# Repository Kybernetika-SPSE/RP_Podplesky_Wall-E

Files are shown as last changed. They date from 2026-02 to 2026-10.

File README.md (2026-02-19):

# WALL-E Replica (Ročníkový Projekt)

Toto je repozitář pro stavbu funkční repliky robota WALL-E. Projekt klade důraz na robustní mechanickou konstrukci a moderní elektroniku.

## 🛠️ O Projektu
Cílem je vytvořit **Repliku robota Wall-E**, pomocí 3D tisku a obráběného kovu
*   **Šasi:** Ocelové pláty (Laser cut) + 3D tisk
*   **Podvozek:** Pásový system s nezávislým odpružením 
*   **Mozek:** Nvidia Jetson Orin Nano

## ⚙️ Hardware Specifikace
*   **Pohon:** 2x Motor JGB37-550 (12V, 160 RPM)
*   **Drivery:** 2x BTS7960B (43A H-Bridge)
*   **PWM Řízení:** PCA9685 (I2C)
*   **Napájení:** Duální systém (2x Li-Po 3S 3500mAh)
*   **Ovládání:** Bezdrátová myš / Gamepad

## 💻 Software
Software běží na **Nvidia Jetson** v jazyce **C++**.
*   Využívá **I2C** pro komunikaci s PCA9685.
*   Čte vstupy z `/dev/input/eventX` (myš/klávesnice).
*   Implementuje **Smooth Start/Stop** pro plynulý rozjezd pásů.
*   Zdrojové kódy naleznete ve složce [`code/`](./code).

## 📂 Struktura Repozitáře
*   [`code/`](./code) - Zdrojové kódy ovládacího softwaru (C++, CMake).
*   [`Dokumentace/`](./Dokumentace) - Technické specifikace, schémata zapojení a plány.
*   [`MODEL/`](./MODEL) - 3D Modely (Inventor/STEP) a podklady pro tisk.
*   [`komponenty.md`](./komponenty.md) - Seznam použitých dílů (BOM).

---
**Status:** 🚧 Ve vývoji (Mechanika 60%, Elektronika 40%, Software 20%)

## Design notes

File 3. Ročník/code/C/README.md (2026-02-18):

# WALL-E Jetson Control Code

This directory contains the C++ control software for the WALL-E robot using Nvidia Jetson.

## Requirements
*   **Hardware:**
    *   Nvidia Jetson (Nano / Orin Nano)
    *   PCA9685 PWM Driver (Connected via I2C Bus 1)
    *   SteelSeries Rival 3 Wireless Mouse (or compatible)
    *   BTS7960 Motor Drivers

*   **Software Dependencies:**
    *   `i2c-tools` & `libi2c-dev`
    *   `libevdev-dev`
    *   `cmake`
    *   `g++`

    Install command:
    ```bash
    sudo apt-get update
    sudo apt-get install -y i2c-tools libi2c-dev libevdev-dev cmake g++
    ```

## Wiring (PCA9685)
*   **SDA:** Pin 3 (Bus 1)
*   **SCL:** Pin 5 (Bus 1)
*   **VCC:** 3.3V
*   **GND:** GND
*   **Motor L:** Channel 0 (Fwd), Channel 1 (Bwd)
*   **Motor R:** Channel 2 (Fwd), Channel 3 (Bwd)

## How to Build
1.  Navigate to this directory:
    ```bash
    cd /path/to/wall-e/code
    ```
2.  Create build directory:
    ```bash
    mkdir build && cd build
    ```
3.  Run CMake:
    ```bash
    cmake ..
    ```
4.  Compile:
    ```bash
    make
    ```

## How to Run
You need to find the specific event device for your mouse.
List devices:
```bash
ls /dev/input/by-id/
```
Look for something like `usb-SteelSeries_Rival_3_Wireless-event-mouse`.

Run the program (needs root for I2C and Input access):
```bash
sudo ./walle_control /dev/input/by-id/usb-SteelSeries_Rival_3_Wireless-event-mouse
```

## Controls
*   **Left Click:** Move Forward (Smooth Acceleration)
*   **Right Click:** Move Backward
*   **Scroll Up:** Turn Left
*   **Scroll Down:** Turn Right

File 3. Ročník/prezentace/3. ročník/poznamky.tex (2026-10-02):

\documentclass[12pt,a4paper]{article}
\usepackage[utf8]{inputenc}
\usepackage[czech]{babel}
\usepackage[left=2cm,right=2cm,top=2cm,bottom=2cm]{geometry}
\usepackage{enumitem}

\begin{document}
\thispagestyle{empty}

\begin{center}
\Huge \textbf{Wall-E: Osnova obhajoby}
\end{center}
\vspace{1em}

% Celý text uděláme obrovský, ať to na pultíku přečteš i na půl metru
\Large

\section*{1. Úvod}
\begin{itemize}[itemsep=0.5em, label=$\rightarrow$]
    \item Přivítání.
    \item \textbf{8kg ocelový stroj} (žádná hračka).
    \item Vše od nuly: CAD $\rightarrow$ Výroba $\rightarrow$ Kód.
\end{itemize}

\section*{2. Podvozek (Delta)}
\begin{itemize}[itemsep=0.5em, label=$\rightarrow$]
    \item \textbf{Výhoda:} Nízké těžiště $\rightarrow$ náklon \textbf{$> 50^\circ$}.
    \item \textbf{Nevýhoda:} Extrémní tření při otáčení na místě.
\end{itemize}

\section*{3. 3D tisk v terénu}
\begin{itemize}[itemsep=0.5em, label=$\rightarrow$]
    \item Pásy: \textbf{PETG} (C-háky).
    \item \textbf{Rizika:} 
        \begin{itemize}
            \item \textbf{Abraze} (obrušování o beton).
            \item \textbf{Kamínky} v kloubech = prasknutí.
        \end{itemize}
    \item \textit{[PODAT KOMISI PÁS DO RUKY]}
\end{itemize}

\section*{4. Zapojení a Soft-start}
\begin{itemize}[itemsep=0.5em, label=$\rightarrow$]
    \item Oddělené obvody (Logika vs. Výkon).
    \item Mozek: \textbf{ESP32-S3} / Svaly: \textbf{Pololu 100:1}.
    \item \textbf{Soft-start:} Plynulý rozjezd v C++. Zabraňuje stržení převodovek rázem!
    \item Ovládání: Vlastní Python skript.
\end{itemize}

\section*{5. Budoucnost (AI)}
\begin{itemize}[itemsep=0.5em, label=$\rightarrow$]
    \item Upgrade z RC auta na \textbf{autonomii}.
    \item \textbf{Kamery + AI:} Trénink rozeznání mé postavy.
    \item Cíl: Režim \textbf{"Follow Me"}.
\end{itemize}

\section*{6. Závěr}
\begin{itemize}[itemsep=0.5em, label=$\rightarrow$]
    \item Cíl splněn (strojařina + programování).
    \item Děkuji p. Jedličkovi.
    \item Dotazy?
\end{itemize}

\end{document}

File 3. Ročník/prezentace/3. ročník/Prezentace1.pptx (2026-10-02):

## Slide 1

[1] BIO OKO. VALL-I (WALL-E) [online]. Praha: Bio Oko [cit. 2026-06-11]. Dostupné z: https://biooko.net/filmy/katalog/wall-e

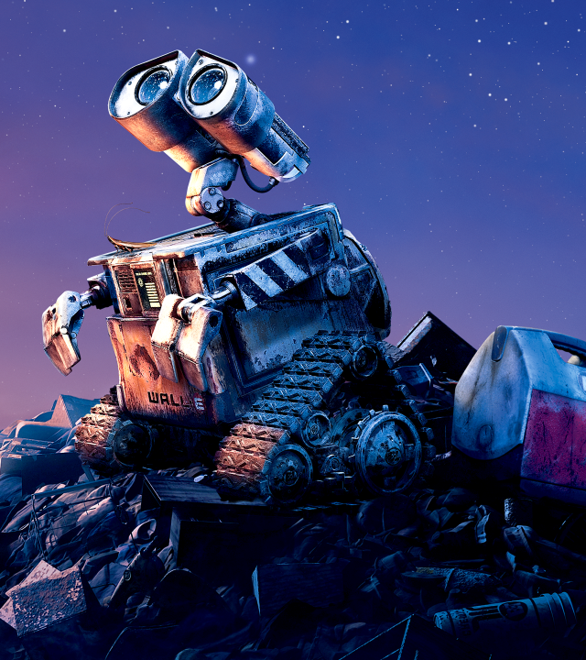
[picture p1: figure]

Návrh a konstrukce modelu robota Wall-E

Konstrukce, pásy, řídící systém
Tomáš Podpleský 3.M

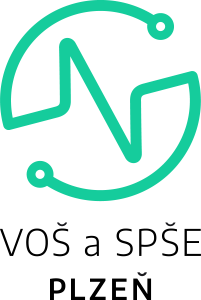
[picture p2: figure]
Titulní stránka | VOŠ a SPŠE Plzeň
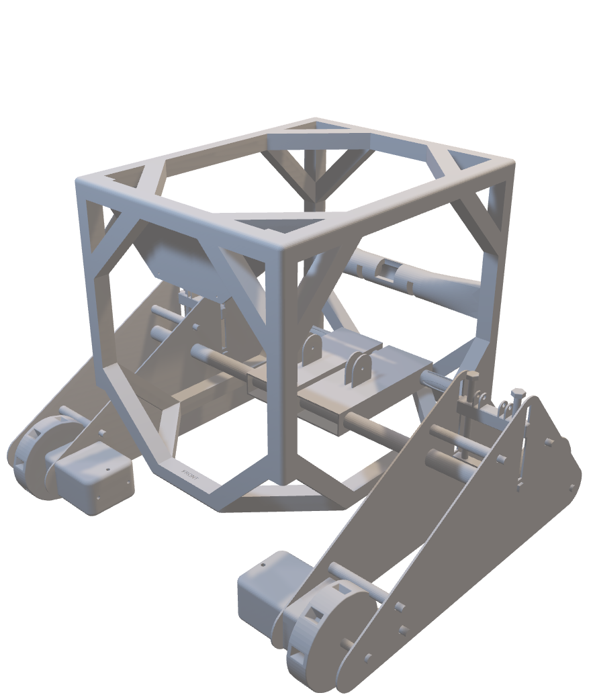
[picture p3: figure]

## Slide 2

Návrh a konstrukce modelu robota Wall-E

Pásy, konstrukce, materiál, řídící systém
Tomáš Podpleský 3.M

Vývoj

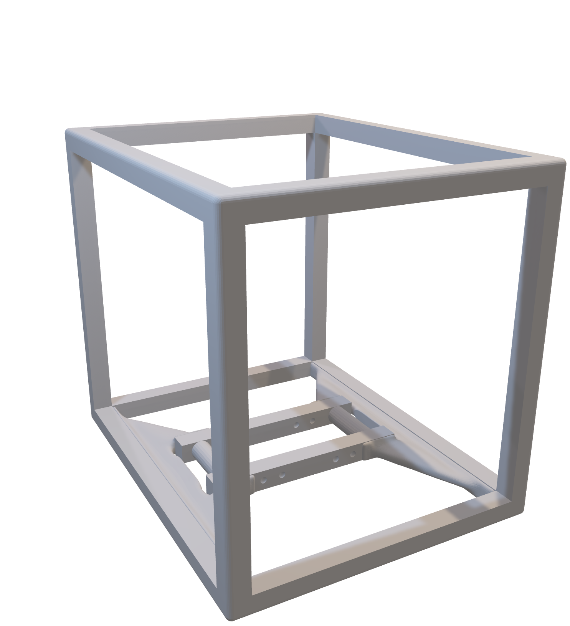
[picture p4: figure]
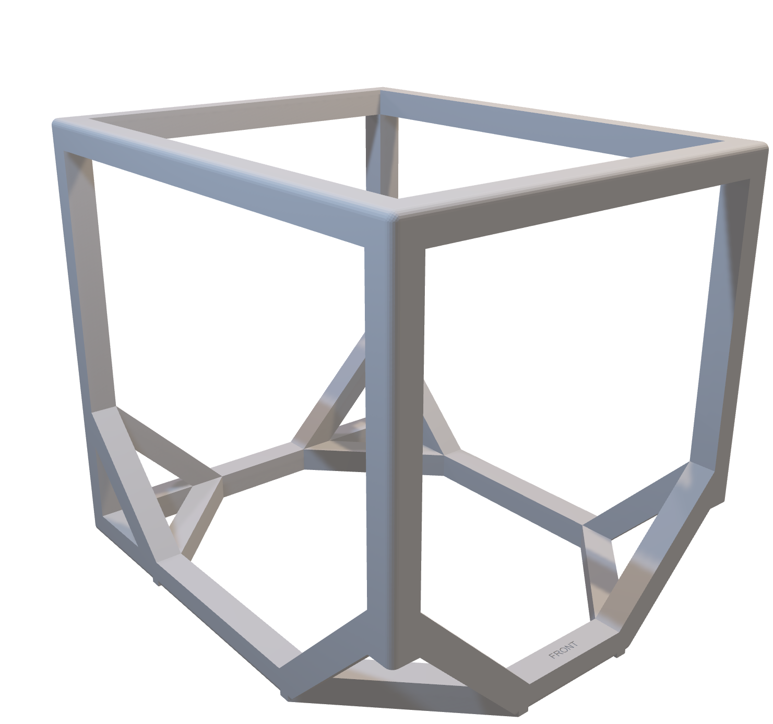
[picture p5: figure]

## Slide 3

Vývoj

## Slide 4

Vývoj

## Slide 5

Vývoj

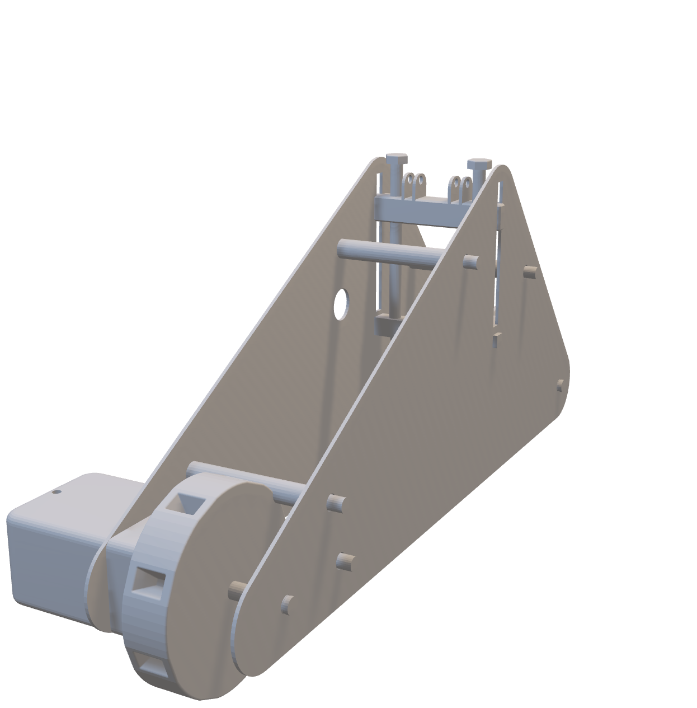
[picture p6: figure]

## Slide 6

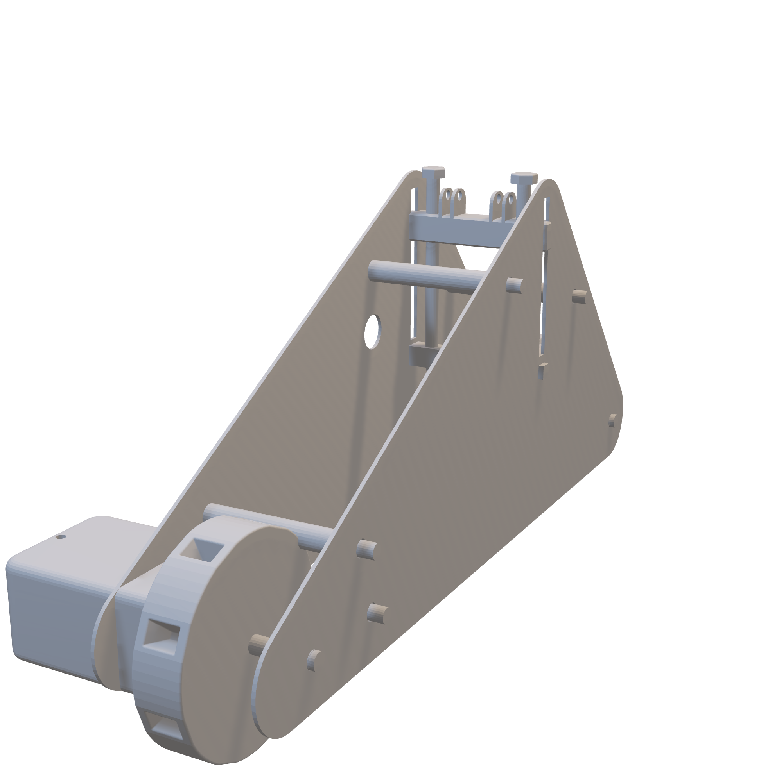
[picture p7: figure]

Mechanika pásů

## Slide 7

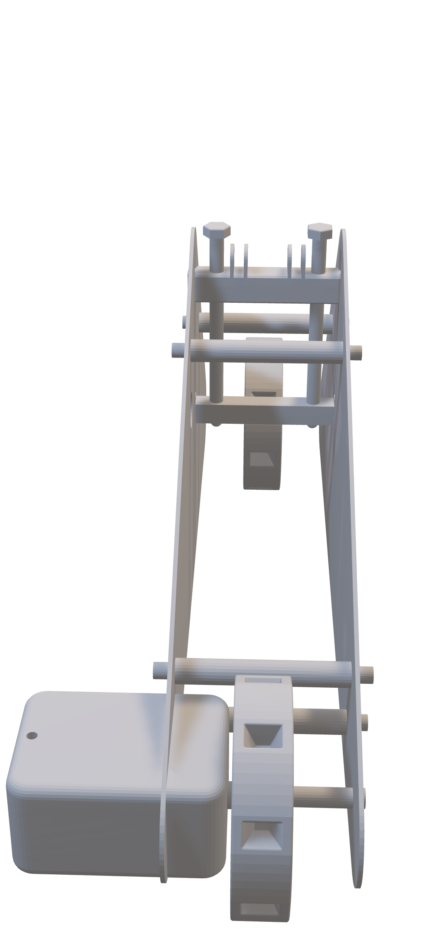
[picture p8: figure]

Mechanika pásů

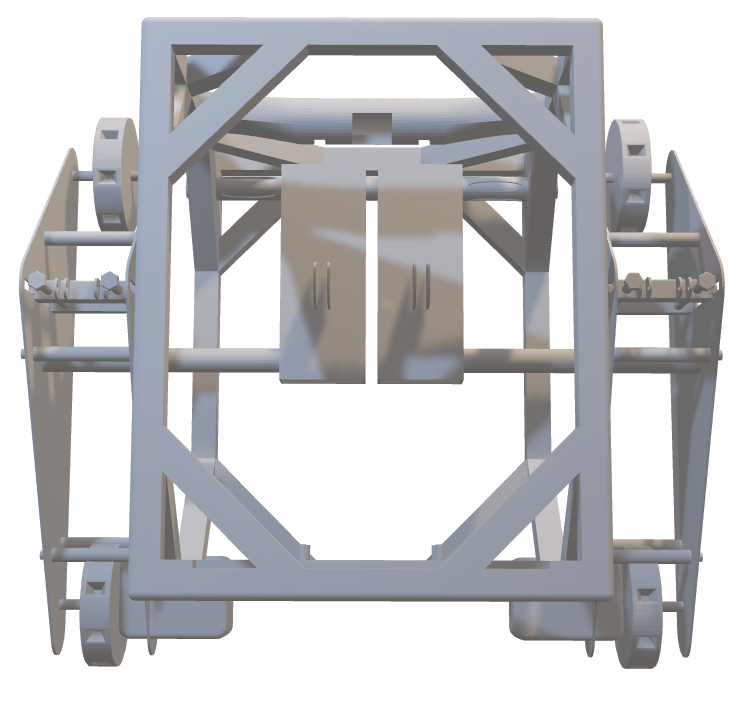
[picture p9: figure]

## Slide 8

Pásy

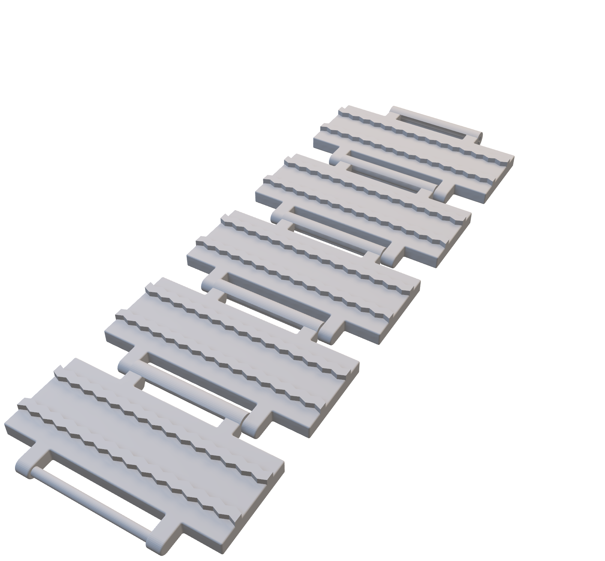
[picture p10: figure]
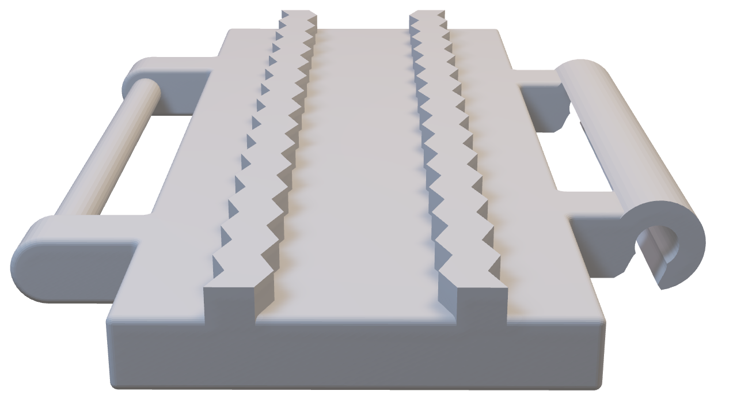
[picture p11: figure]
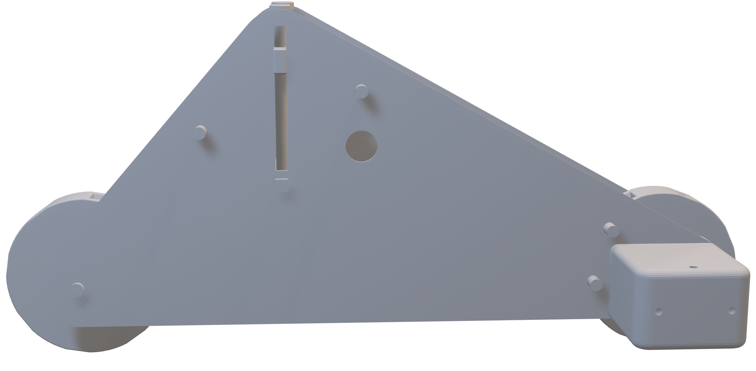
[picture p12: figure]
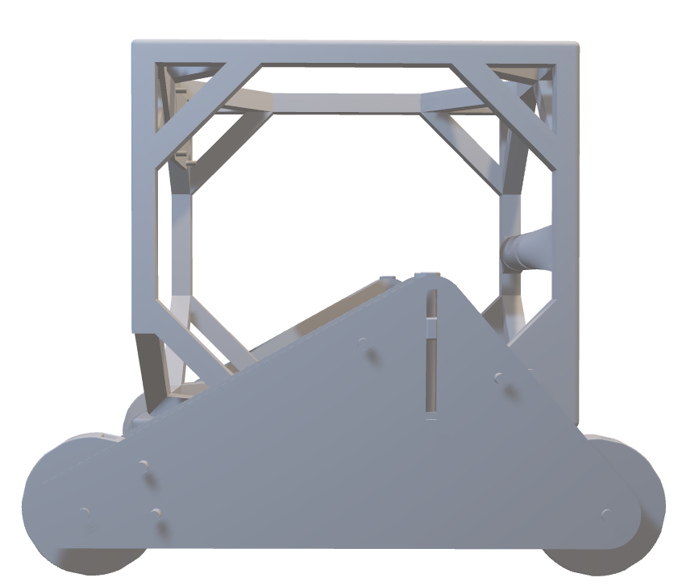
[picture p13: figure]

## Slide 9

Pásy

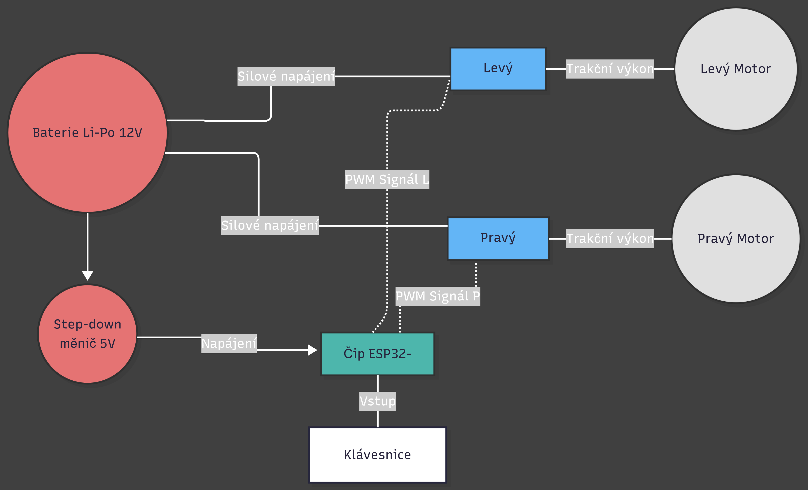
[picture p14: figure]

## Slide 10

Budoucnost a autonomní řízení

Výkonnější čip a AI
Kamery a senzory
Pohyblivé ruce
Vzhled

Návrh zapojení

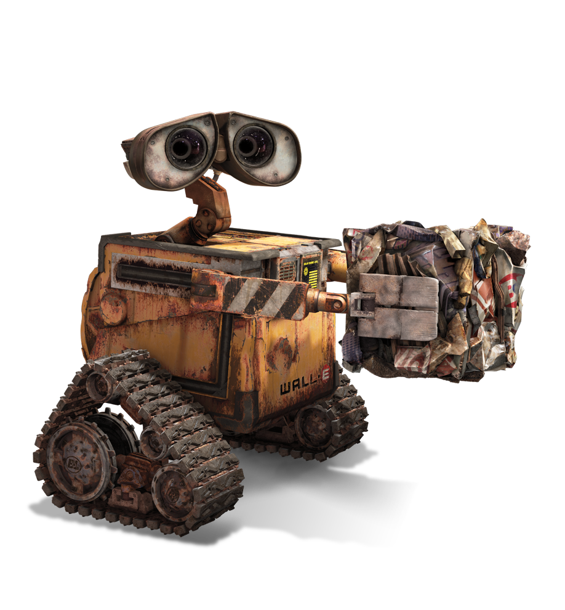
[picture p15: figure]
Wall-E Pic Eve Film Pixar Free Transparent Image HQ Transparent HQ PNG Download | FreePNGimg

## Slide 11

[2] FREEPNGIMG. Wall-e Pic Eve Film Pixar Free Transparent Image HQ [online]. [cit. 2026-06-11]. Dostupné z: https://freepngimg.com/png/65230-wall-e-pic-eve-film-pixar-free-transparent-image-hq

Budoucnost a autonomní řízení

Výkonnější čip a AI
Kamery a senzory
Pohyblivé ruce
Vzhled

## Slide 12

Děkuji vám za pozornost

Nějaké otázky?

Budoucnost a autonomní řízení

Výkonnější čip a AI
Kamery a senzory
Pohyblivé ruce
Vzhled

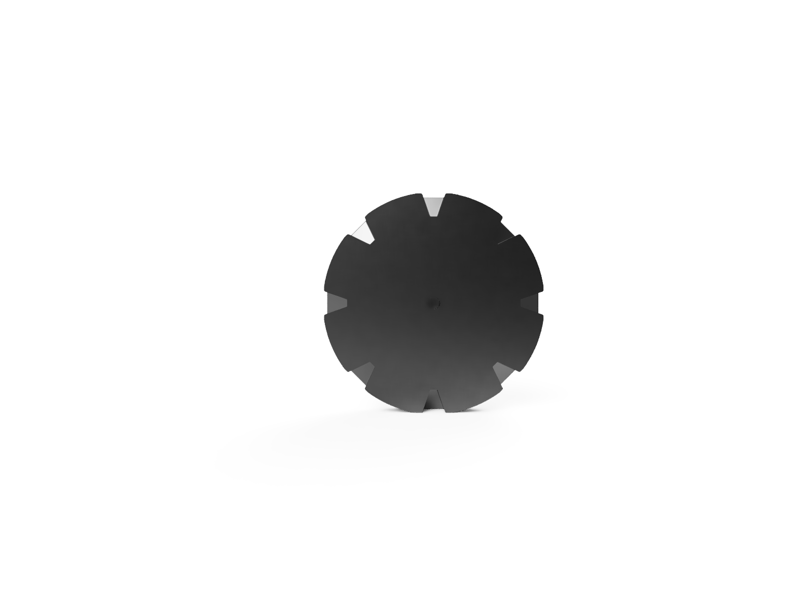
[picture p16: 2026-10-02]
3. Ročník/FOTKY/VODICI_KOLO_REZ_WALL-E.png

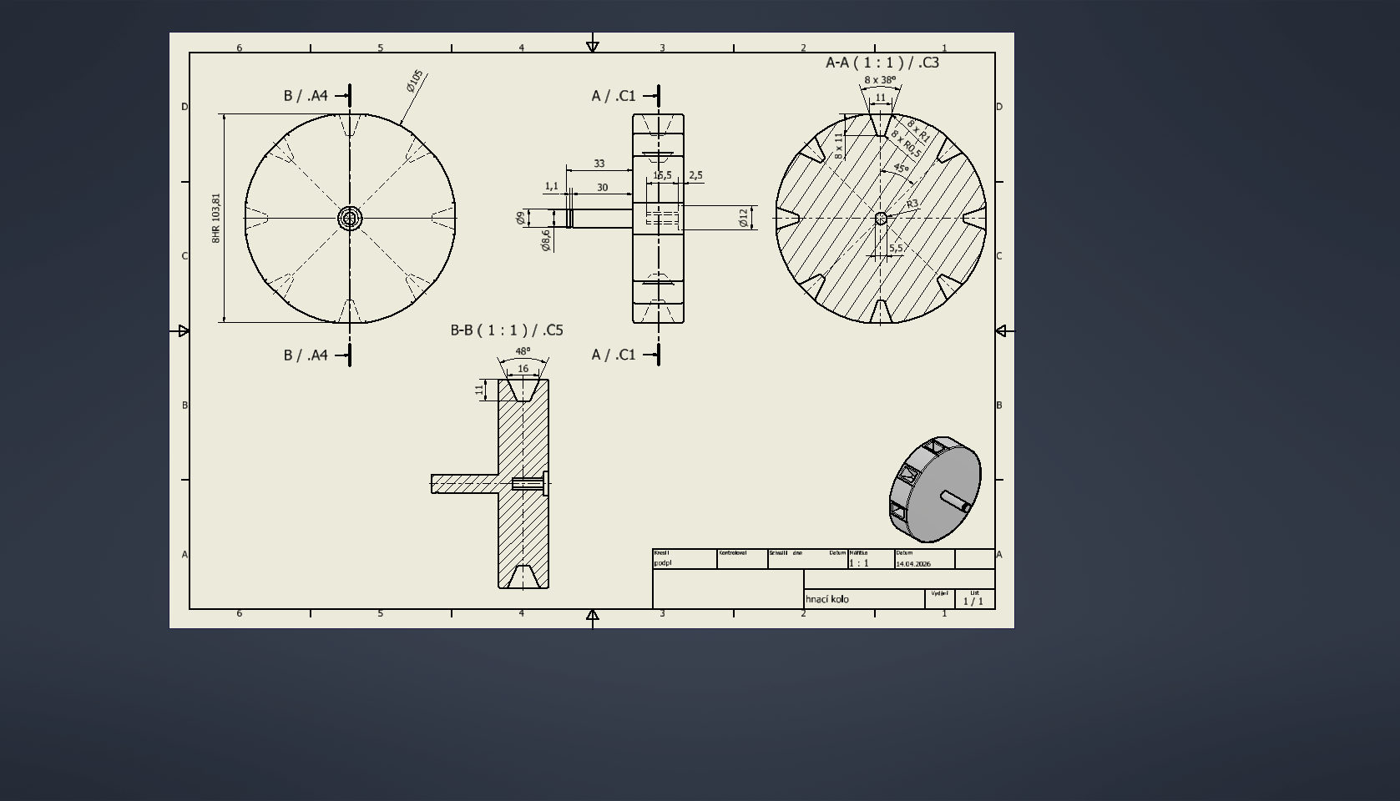
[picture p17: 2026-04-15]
3. Ročník/VÝKRESY/hnací kolo.png

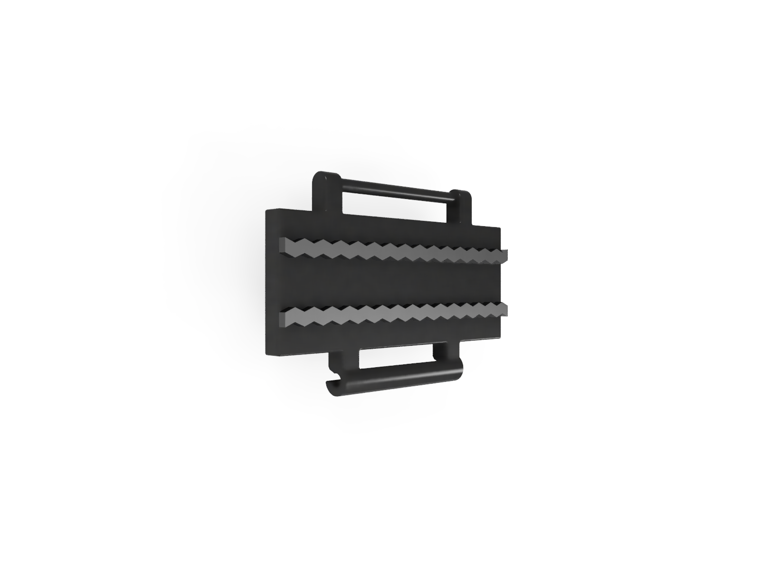
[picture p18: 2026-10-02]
3. Ročník/FOTKY/CLANEK_PASU_WALL-E_2.png

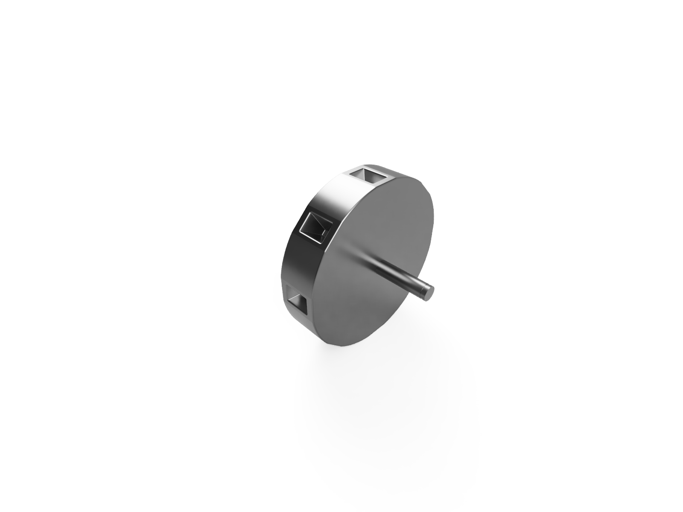
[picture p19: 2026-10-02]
3. Ročník/FOTKY/VODICI_KOLO_WALL-E.png

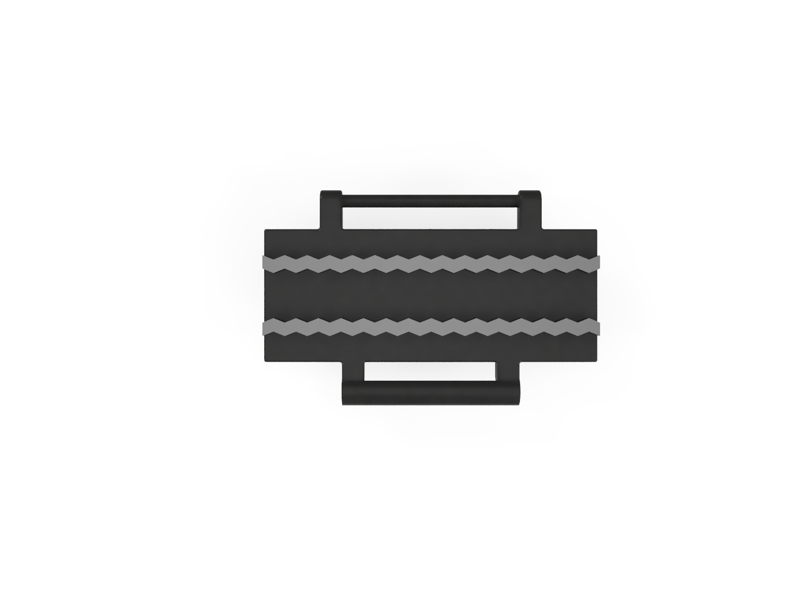
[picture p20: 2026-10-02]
3. Ročník/FOTKY/CLANEK_PASU_WALL-E.png

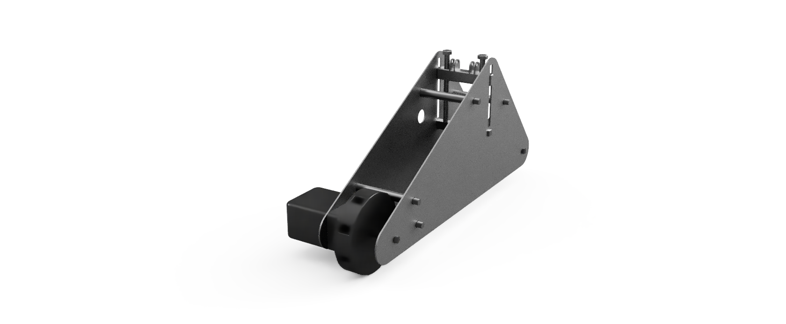
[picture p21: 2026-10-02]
3. Ročník/FOTKY/WALL-E_NAPRAVA.PNG

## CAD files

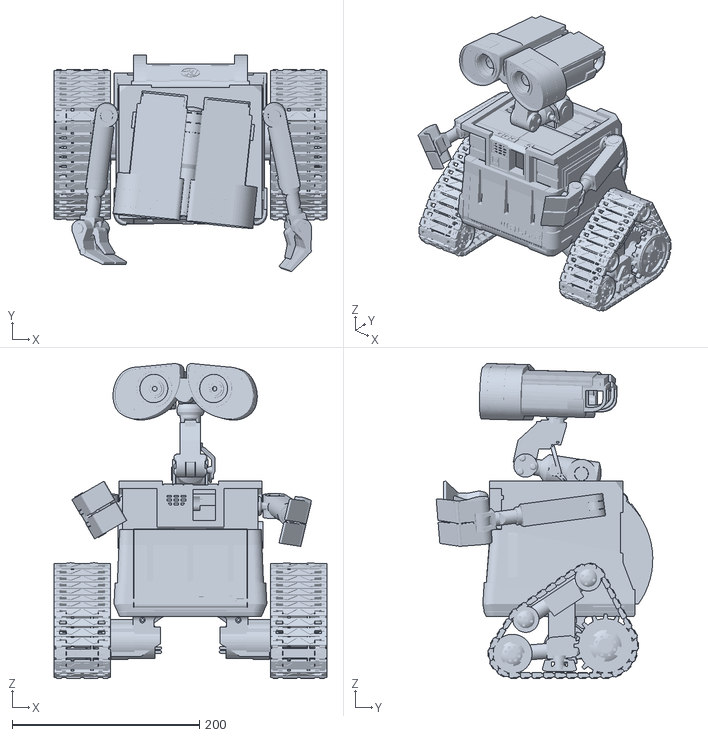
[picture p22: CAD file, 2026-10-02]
3. Ročník/MODEL/Wall-E_Assembly_NotForPrinting.stl
291.5 x 231.6 x 336.8

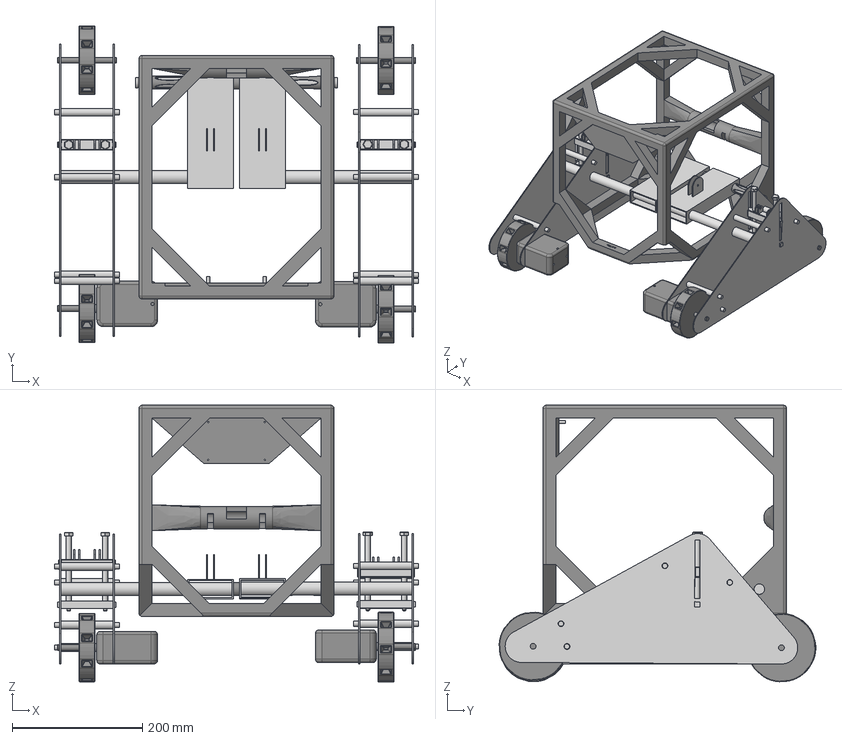
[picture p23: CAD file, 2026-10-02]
3. Ročník/STEP/Příloha II - model robota.step
560.0 x 487.4 x 425.6 mm

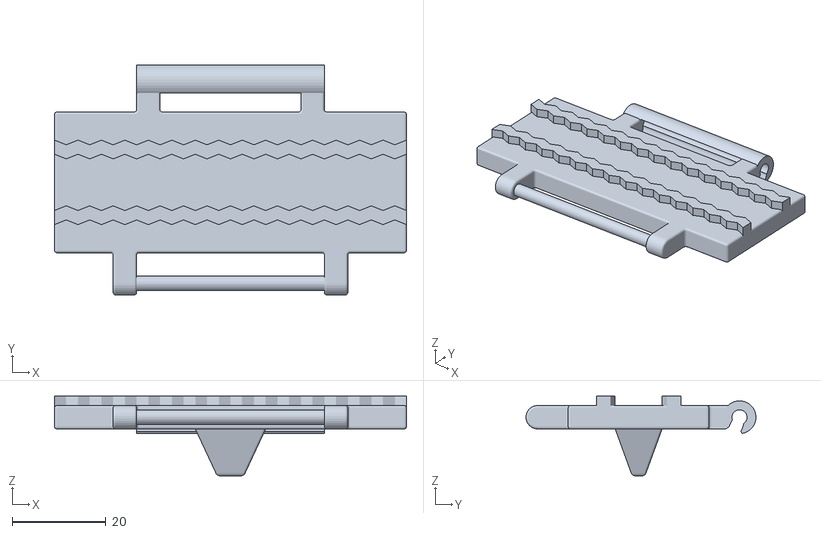
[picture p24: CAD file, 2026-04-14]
3. Ročník/STL/Těleso1.stl
75.0 x 49.0 x 17.0

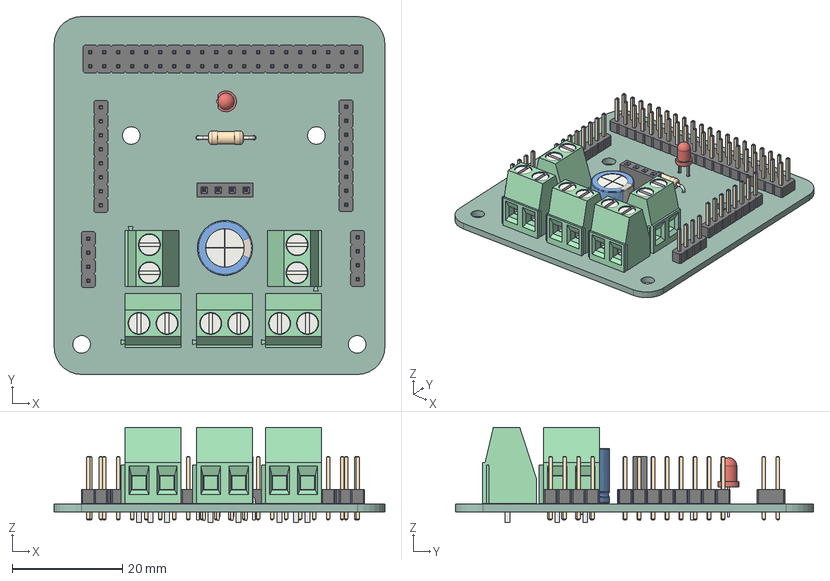
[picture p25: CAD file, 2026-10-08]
4. Ročník/ELEKTRO/PCB/Wall-E Power Hub v1.0.step
60.0 x 65.0 x 17.3 mm
PinHeader_1x08_P2.54mm_Vertical x 2
PinHeader_1x04_P2.54mm_Vertical x 2
LED_D3.0mm
PinHeader_2x20_P2.54mm_Vertical
R_Axial_DIN0207_L6.3mm_D2.5mm_P10.16mm_Horizontal
TerminalBlock_Phoenix_MKDS-1,5-2-5.08_1x02_P5.08mm_Horizontal x 5
PinSocket_1x04_P2.54mm_Vertical
CP_Radial_D10.0mm_P5.00mm
PCB_PCB

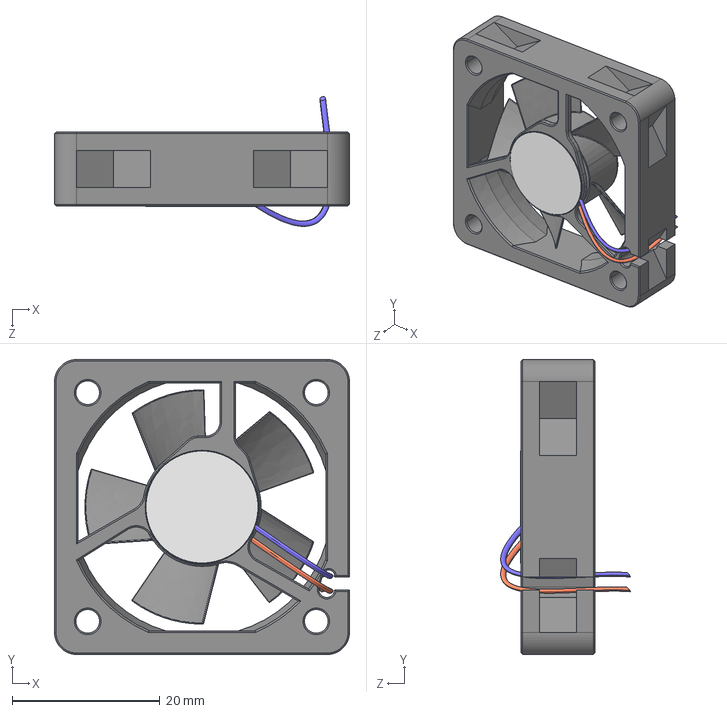
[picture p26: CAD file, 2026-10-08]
4. Ročník/Modely/STEP/кулер 40х40х10.STEP
40.0 x 40.0 x 17.6 mm
корпус 40х40х10
вентилятор

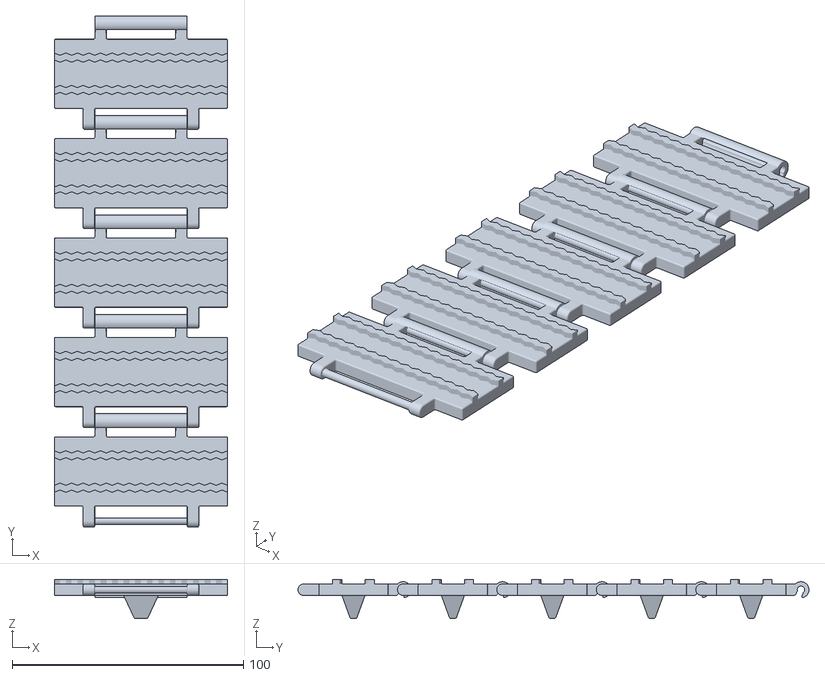
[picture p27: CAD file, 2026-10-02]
3. Ročník/prezentace/3. ročník/Kus pásu.stl
75.0 x 221.0 x 17.0

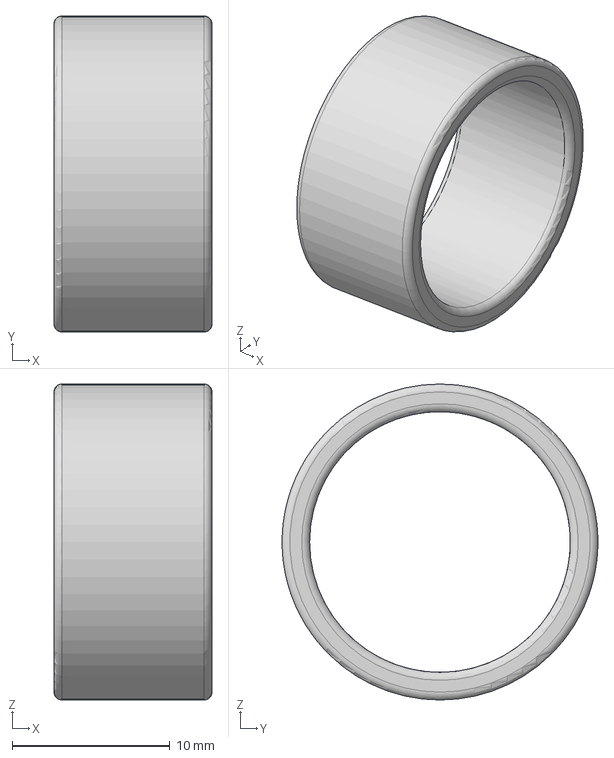
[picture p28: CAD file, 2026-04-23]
3. Ročník/STEP/Distanční váleček 10.step
10.0 x 20.0 x 20.0 mm

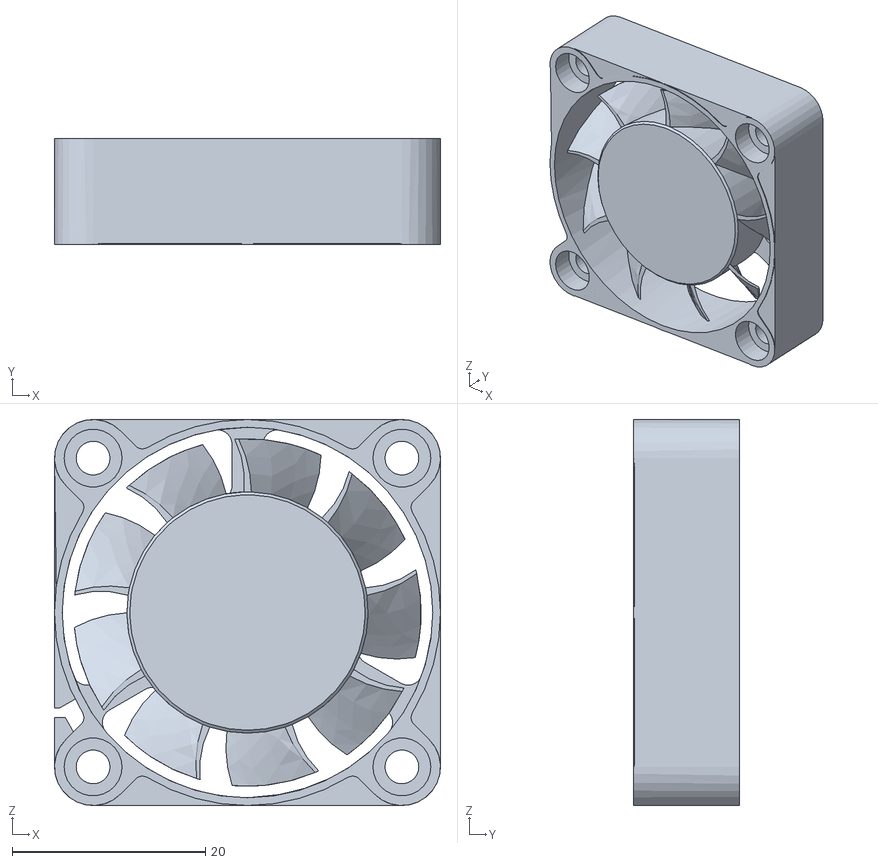
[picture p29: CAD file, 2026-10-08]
4. Ročník/Modely/STEP/DC-Fan-40x40x10.stl
40.0 x 11.0 x 40.0

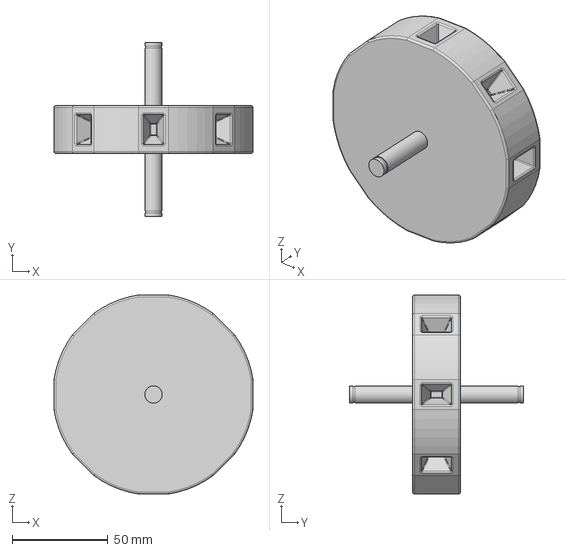
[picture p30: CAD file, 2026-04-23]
3. Ročník/STEP/vodné kolo.step
103.8 x 91.0 x 103.8 mm

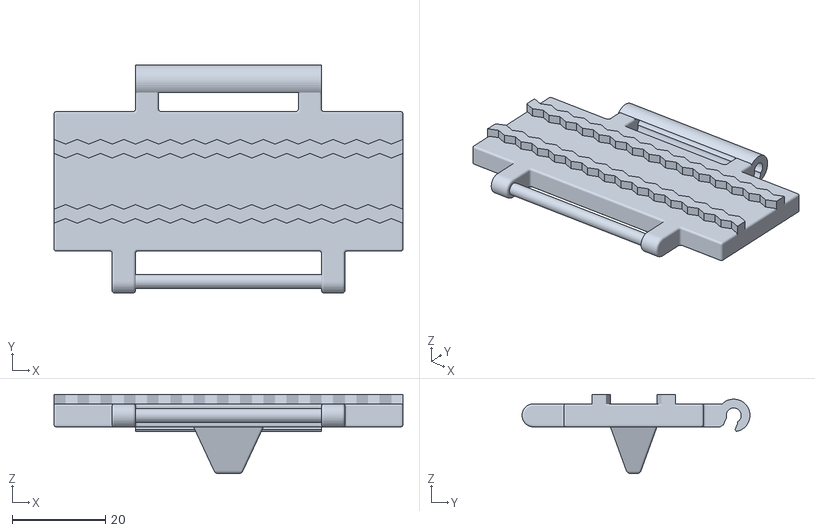
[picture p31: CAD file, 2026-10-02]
3. Ročník/prezentace/3. ročník/Článek pásu.stl
75.0 x 49.0 x 17.0

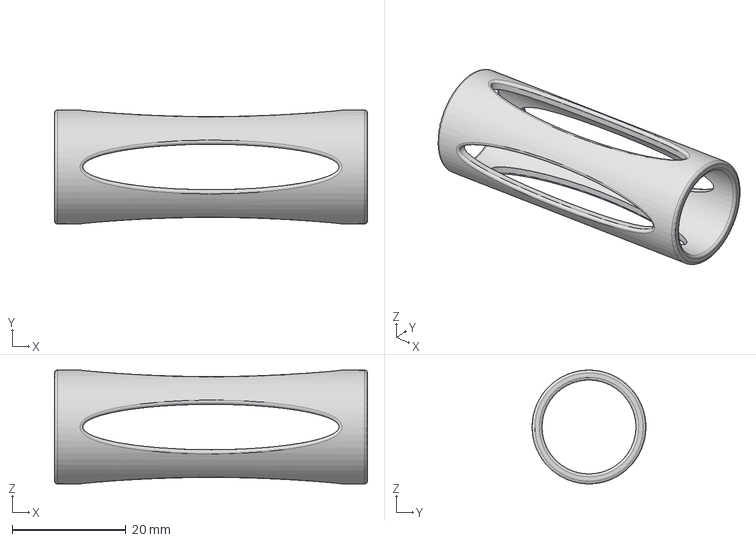
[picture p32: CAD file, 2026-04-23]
3. Ročník/STEP/Distanční váleček 55.step
55.0 x 20.0 x 20.0 mm

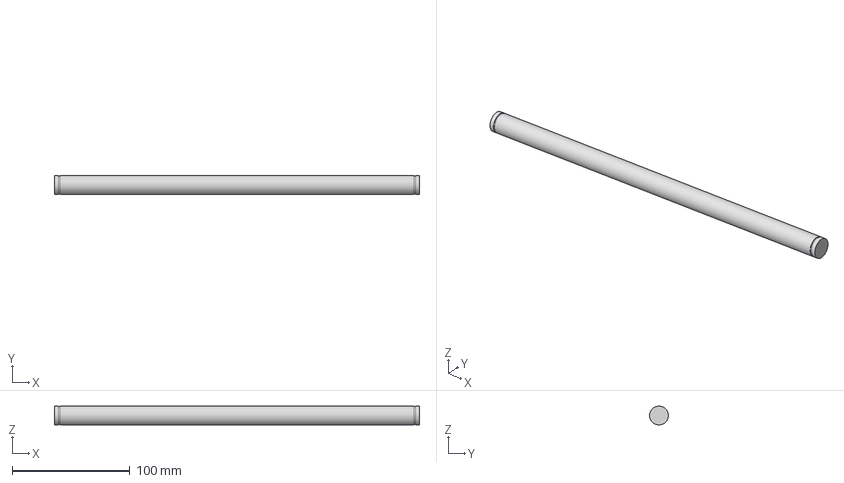
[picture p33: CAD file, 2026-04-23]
3. Ročník/STEP/Tyč nosná.step
310.0 x 16.0 x 16.0 mm

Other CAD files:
3. Ročník/VÝKRESY/vodné kolo.dwg
3. Ročník/VÝKRESY/plát vnitřní.dwg
3. Ročník/prezentace/3. ročník/Wall-e.stl
3. Ročník/VÝKRESY/Šablona.dwg
3. Ročník/VÝKRESY/vzpěra.dwg
3. Ročník/VÝKRESY/plát vnější.dwg
3. Ročník/STEP/Středový jekl.step
3. Ročník/STEP/hnací kolo.step
3. Ročník/STEP/hnací kolo/hnací kolo.ipt
3. Ročník/STEP/kolo zadní_.step
3. Ročník/STEP/kolo zadní_/kolo zadní_.ipt
3. Ročník/STEP/kus horní.step
3. Ročník/STEP/kus horní/kus horní.ipt
3. Ročník/STEP/kus spodní/kus spodní.ipt
3. Ročník/STEP/napínací šroub.step
3. Ročník/STEP/napínací šroub/napínací šroub.ipt
3. Ročník/STEP/napínák.step
3. Ročník/STEP/napínák/napínák/napínák.ipt
3. Ročník/STEP/plát vnitřní.step
3. Ročník/STEP/plát vnitřní/plát vnitřní.ipt
3. Ročník/STEP/plát vnější.step
3. Ročník/STEP/plát vnější/plát vnější.ipt
3. Ročník/STEP/vodné kolo/vodné kolo/vodné kolo.ipt
3. Ročník/STEP/vzpěra.step
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

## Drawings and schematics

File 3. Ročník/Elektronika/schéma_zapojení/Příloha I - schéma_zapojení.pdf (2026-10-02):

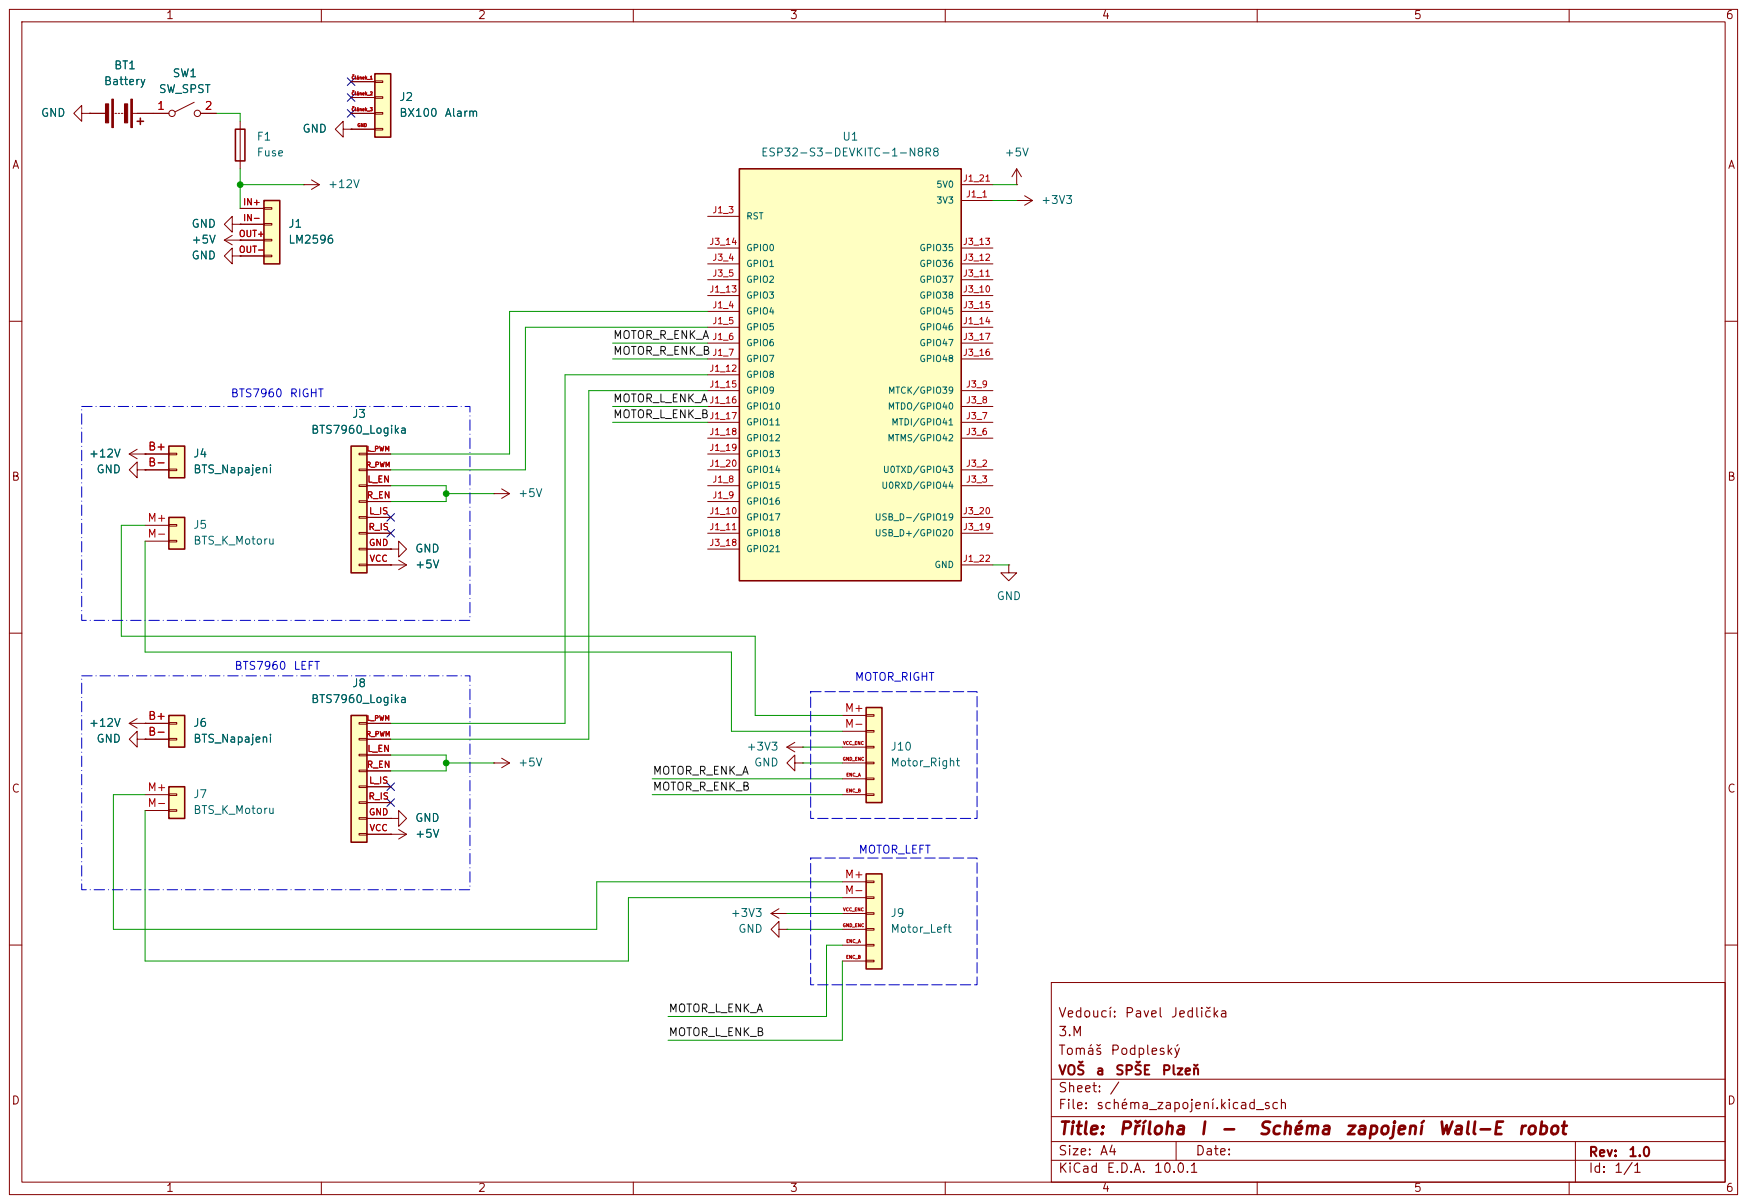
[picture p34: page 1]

Vedoucí: Pavel Jedlička
Tomáš Podpleský
VOŠ a SPŠE Plzeň
Sheet: /
File: schéma_zapojení.kicad_sch
Title: Příloha I - Schéma zapojení Wall-E robot

Size: A4 | Rev: 1.0
KiCad E.D.A. 10.0.1 | Id: 1/1

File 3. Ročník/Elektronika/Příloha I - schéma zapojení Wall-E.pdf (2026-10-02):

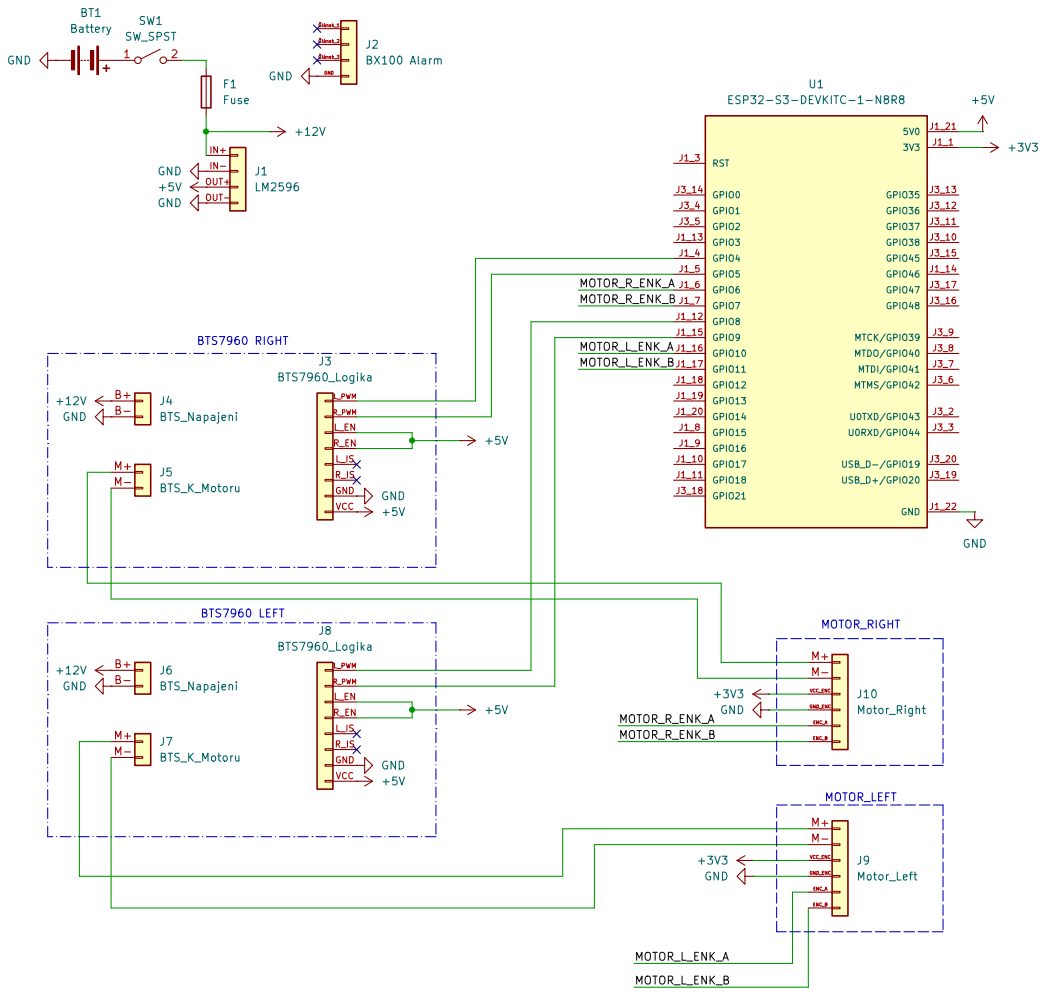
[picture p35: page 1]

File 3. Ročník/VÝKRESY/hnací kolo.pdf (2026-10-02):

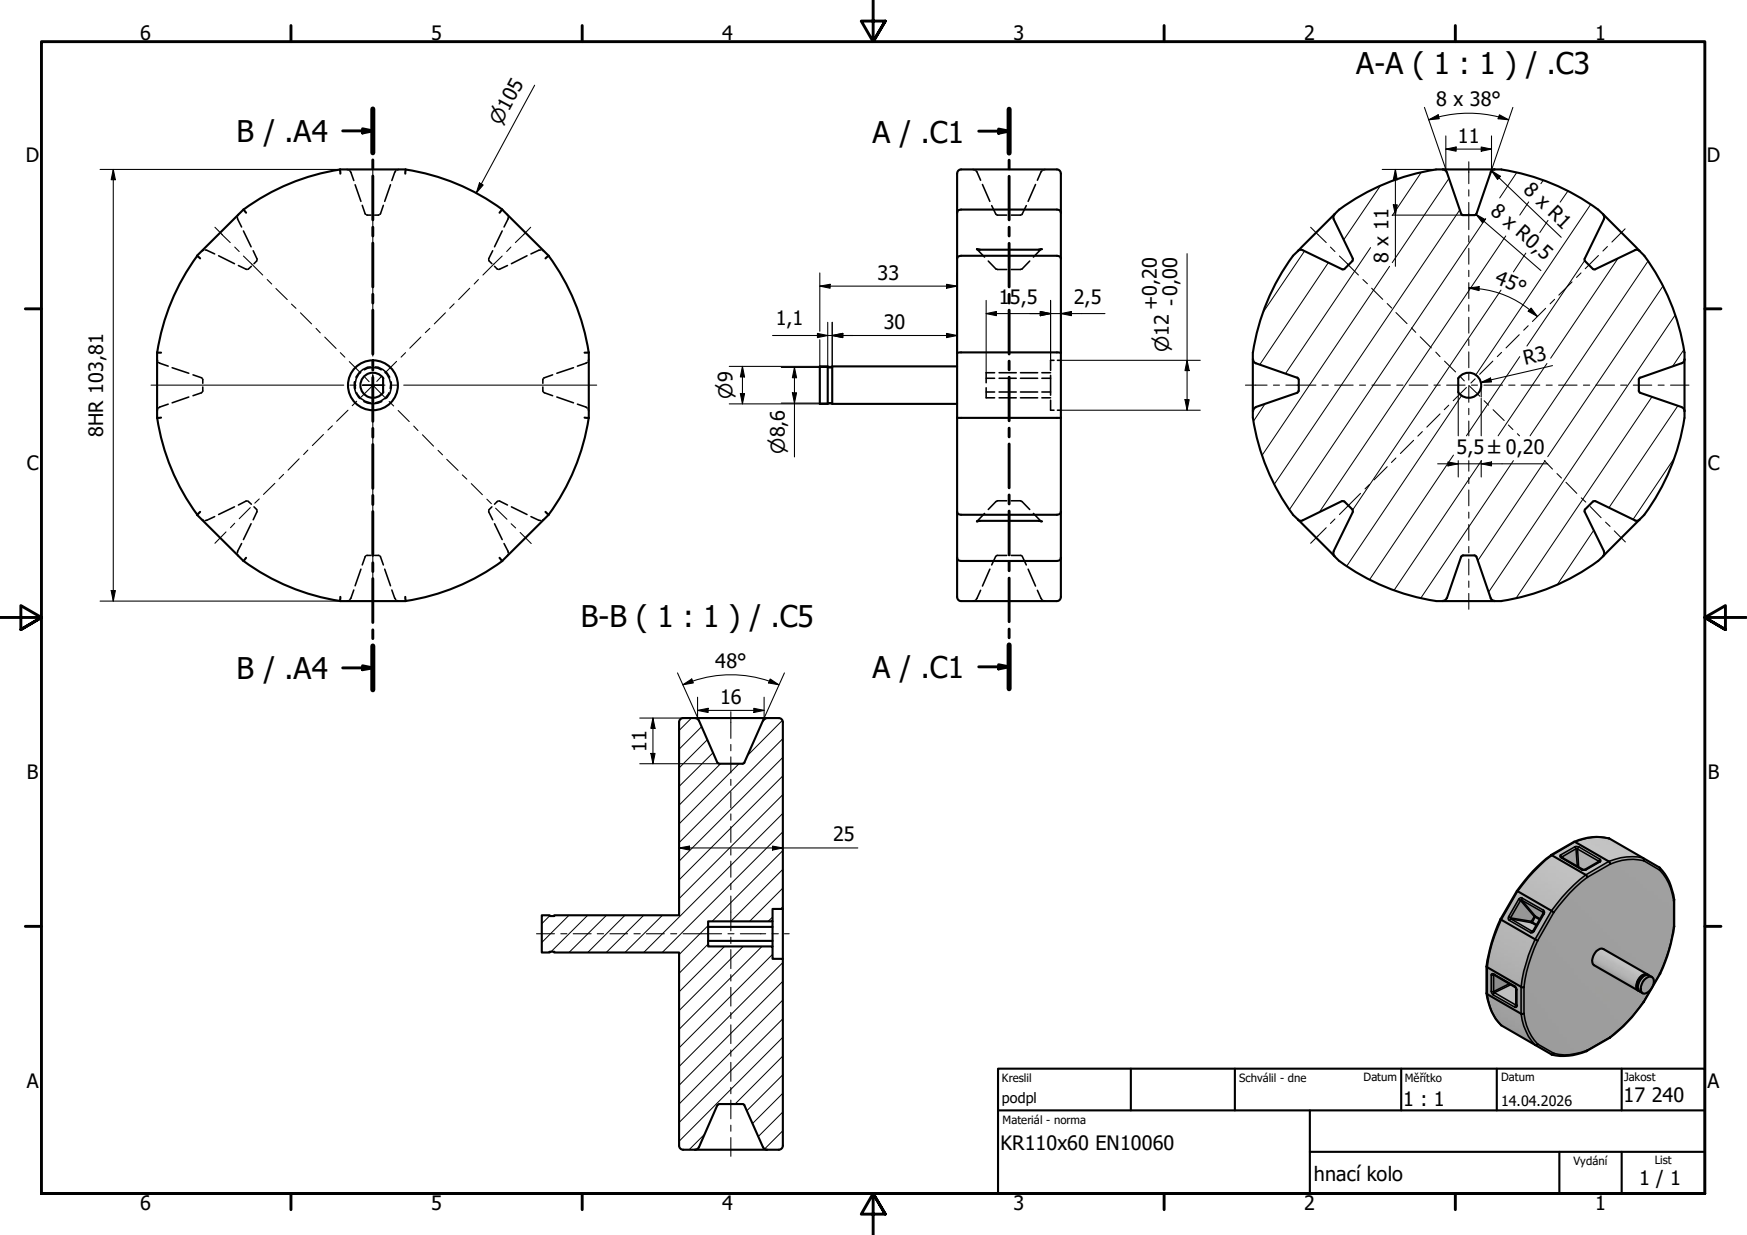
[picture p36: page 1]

Kreslil podpl | Schválil - dne Datum | Měřítko 1 : 1 | Datum 14.04.2026 | Jakost 17 240

Materiál - norma KR110x60 EN10060

hnací kolo | Vydání | List 1 / 1

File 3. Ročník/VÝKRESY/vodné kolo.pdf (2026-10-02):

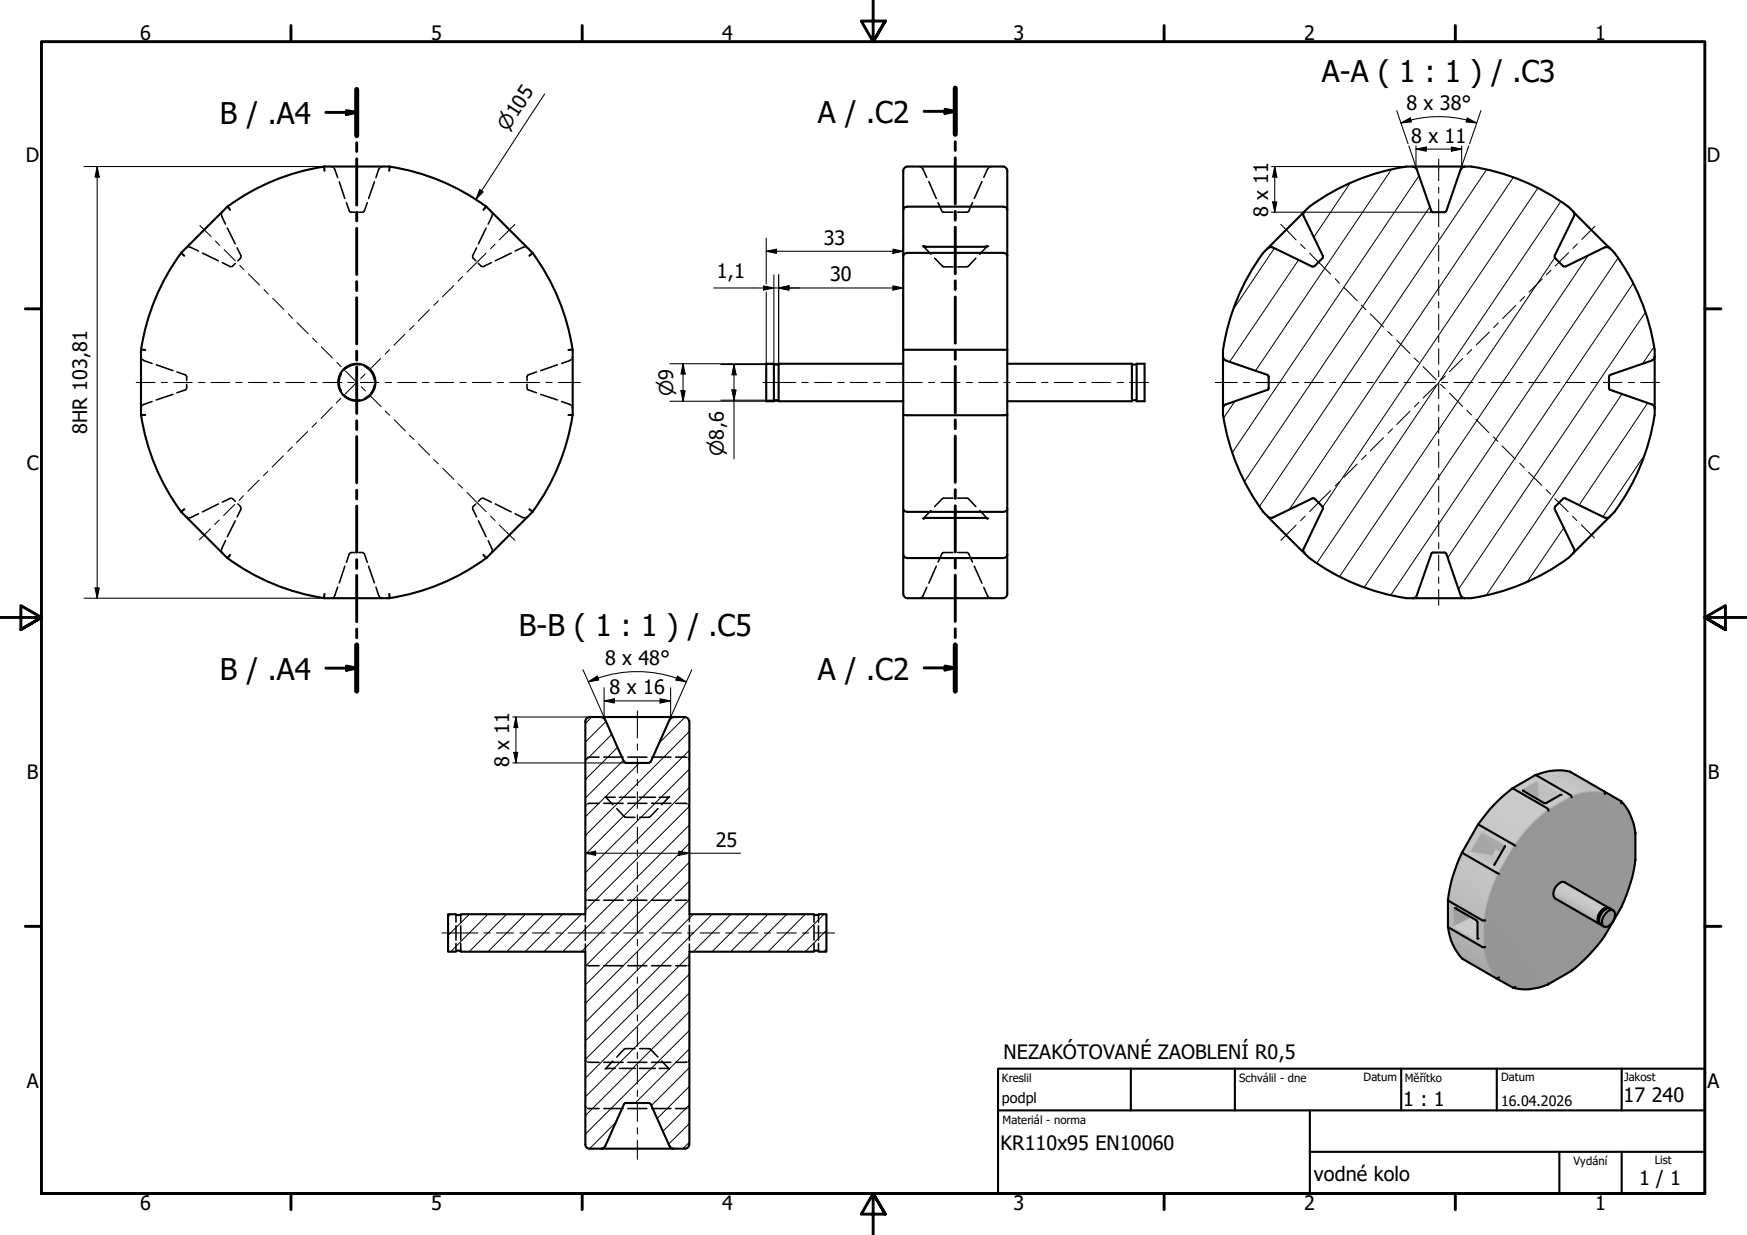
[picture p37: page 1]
NEZAKÓTOVANÉ ZAOBLENÍ R0,5

Kreslil podpl | Schválil - dne Datum | Měřítko 1 : 1 | Datum 16.04.2026 | Jakost 17 240

Materiál - norma KR110x95 EN10060

vodné kolo | Vydání | List 1 / 1

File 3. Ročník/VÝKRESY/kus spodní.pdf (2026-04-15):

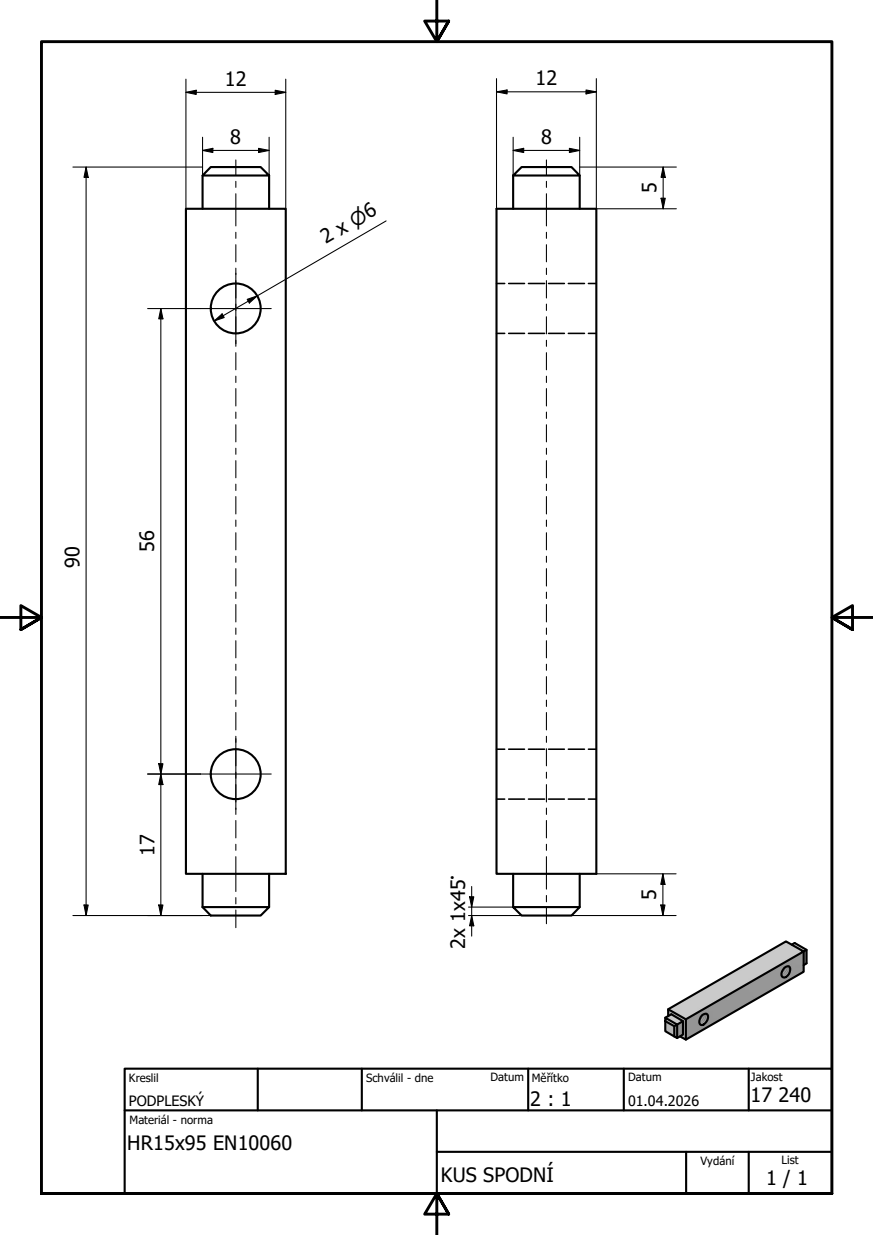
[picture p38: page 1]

Kreslil PODPLESKÝ | Schválil - dne Datum | Měřítko 2 : 1 | Datum 01.04.2026 | Jakost 17 240

Materiál - norma HR15x95 EN10060

KUS SPODNÍ | Vydání | List 1 / 1

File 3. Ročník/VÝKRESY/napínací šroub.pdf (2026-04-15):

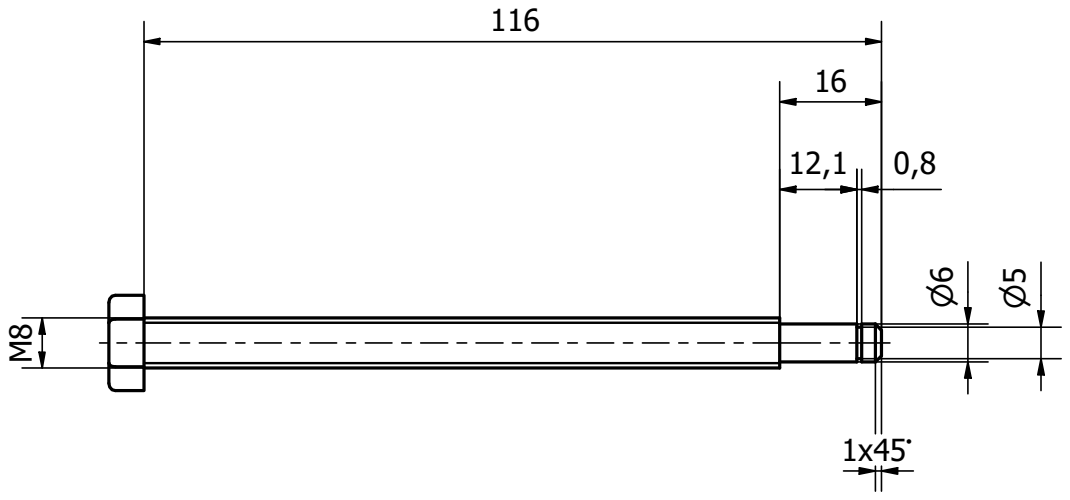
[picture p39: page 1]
napínací šroub; Kreslil; Kontroloval; Schválil - dne; Datum

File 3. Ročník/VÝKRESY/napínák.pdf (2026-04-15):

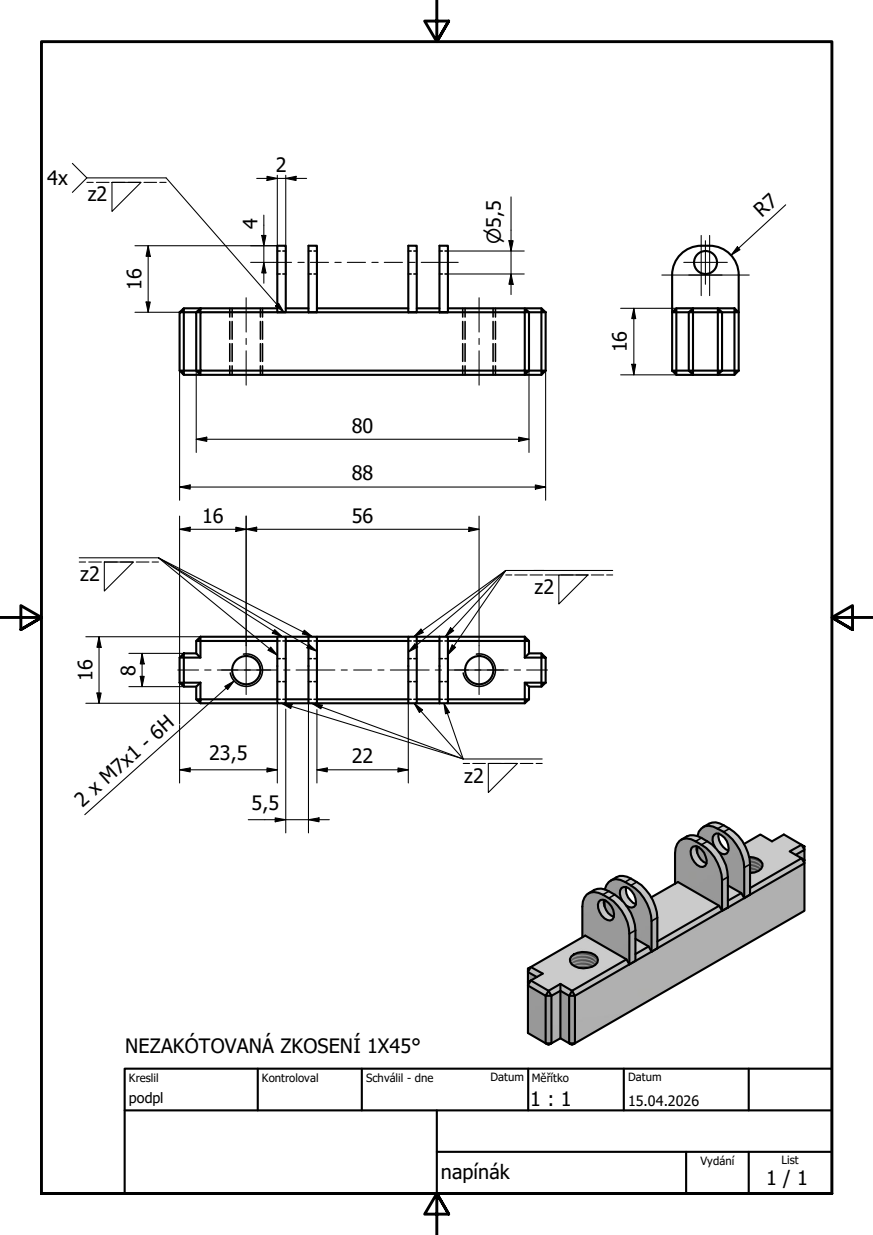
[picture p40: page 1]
Kreslil; Kontroloval; Schválil - dne; Datum; NEZAKÓTOVANÁ ZKOSENÍ 1X45°

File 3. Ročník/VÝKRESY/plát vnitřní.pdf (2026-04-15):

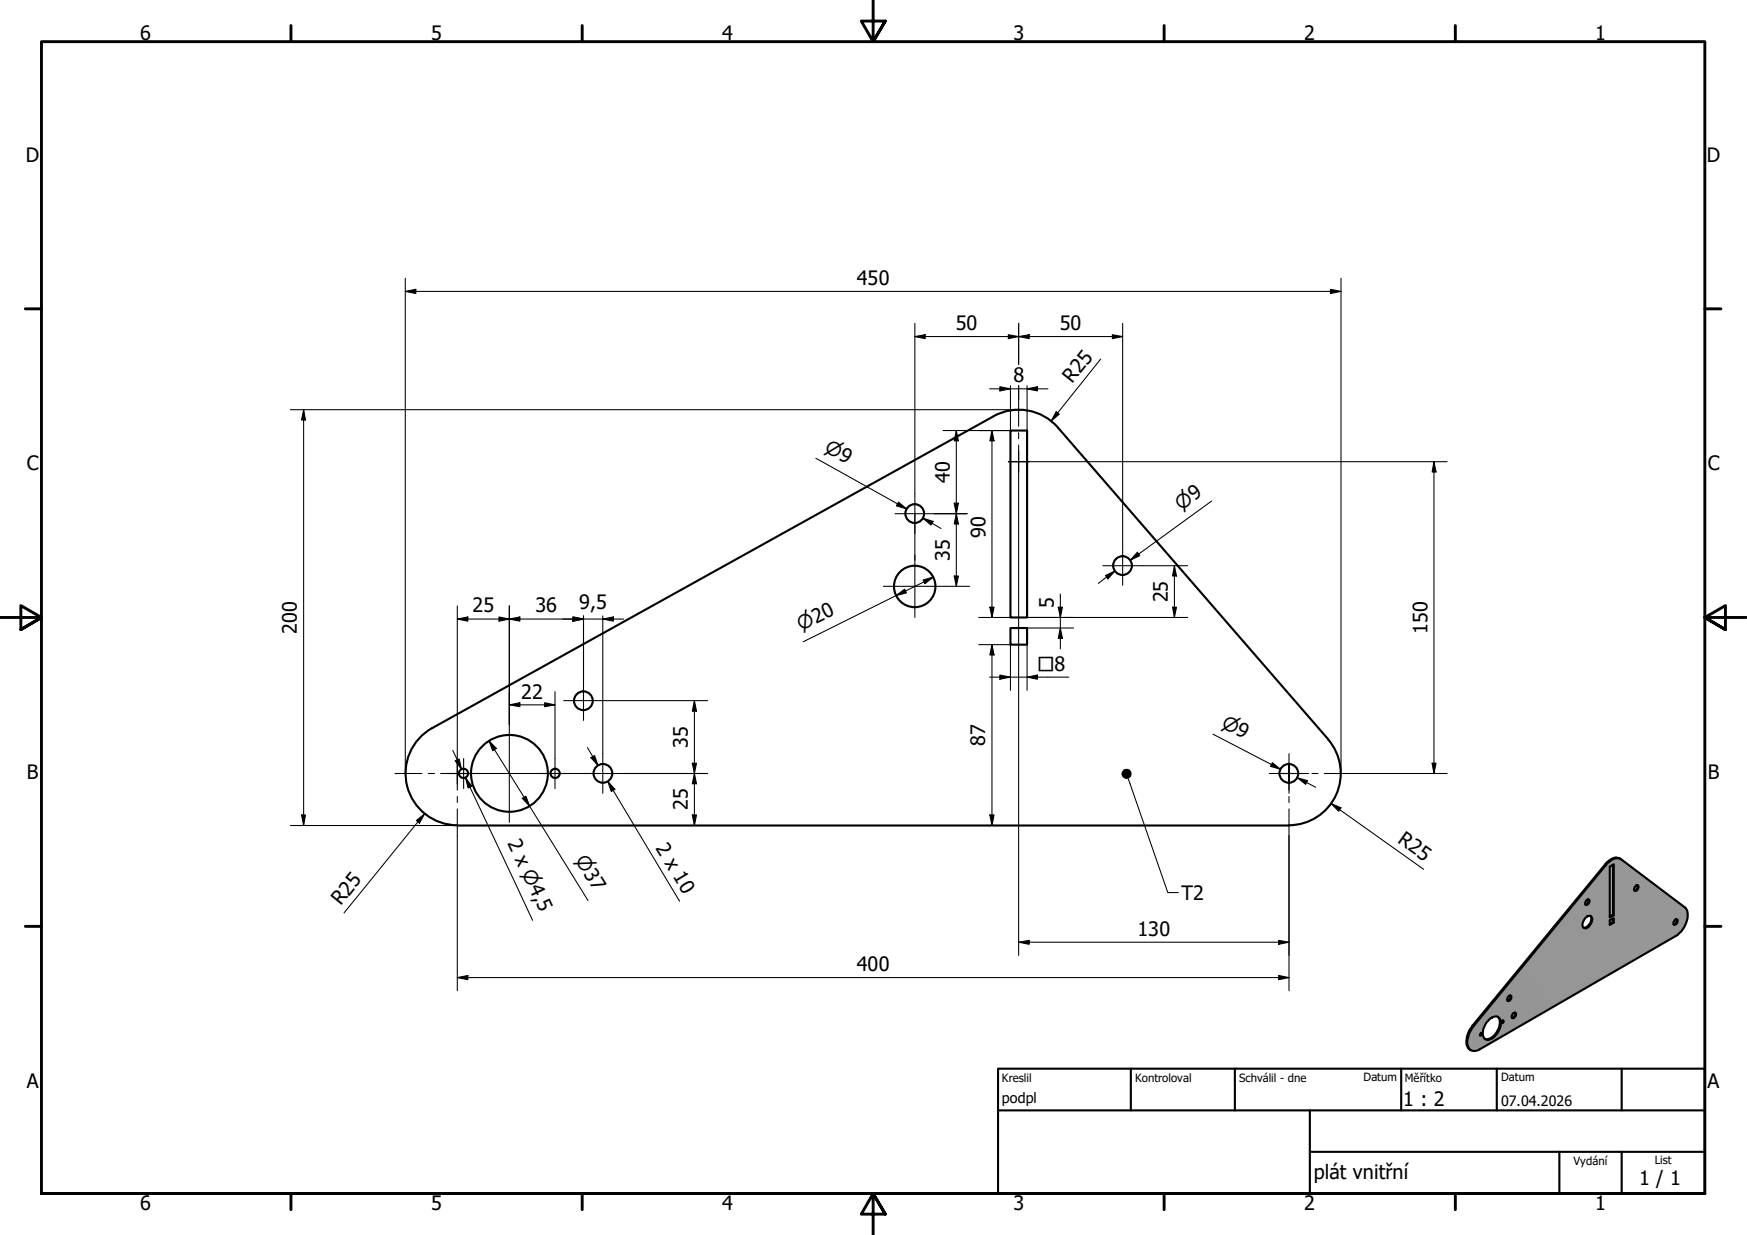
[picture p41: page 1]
plát vnitřní; Kreslil; Kontroloval; Schválil - dne; Datum

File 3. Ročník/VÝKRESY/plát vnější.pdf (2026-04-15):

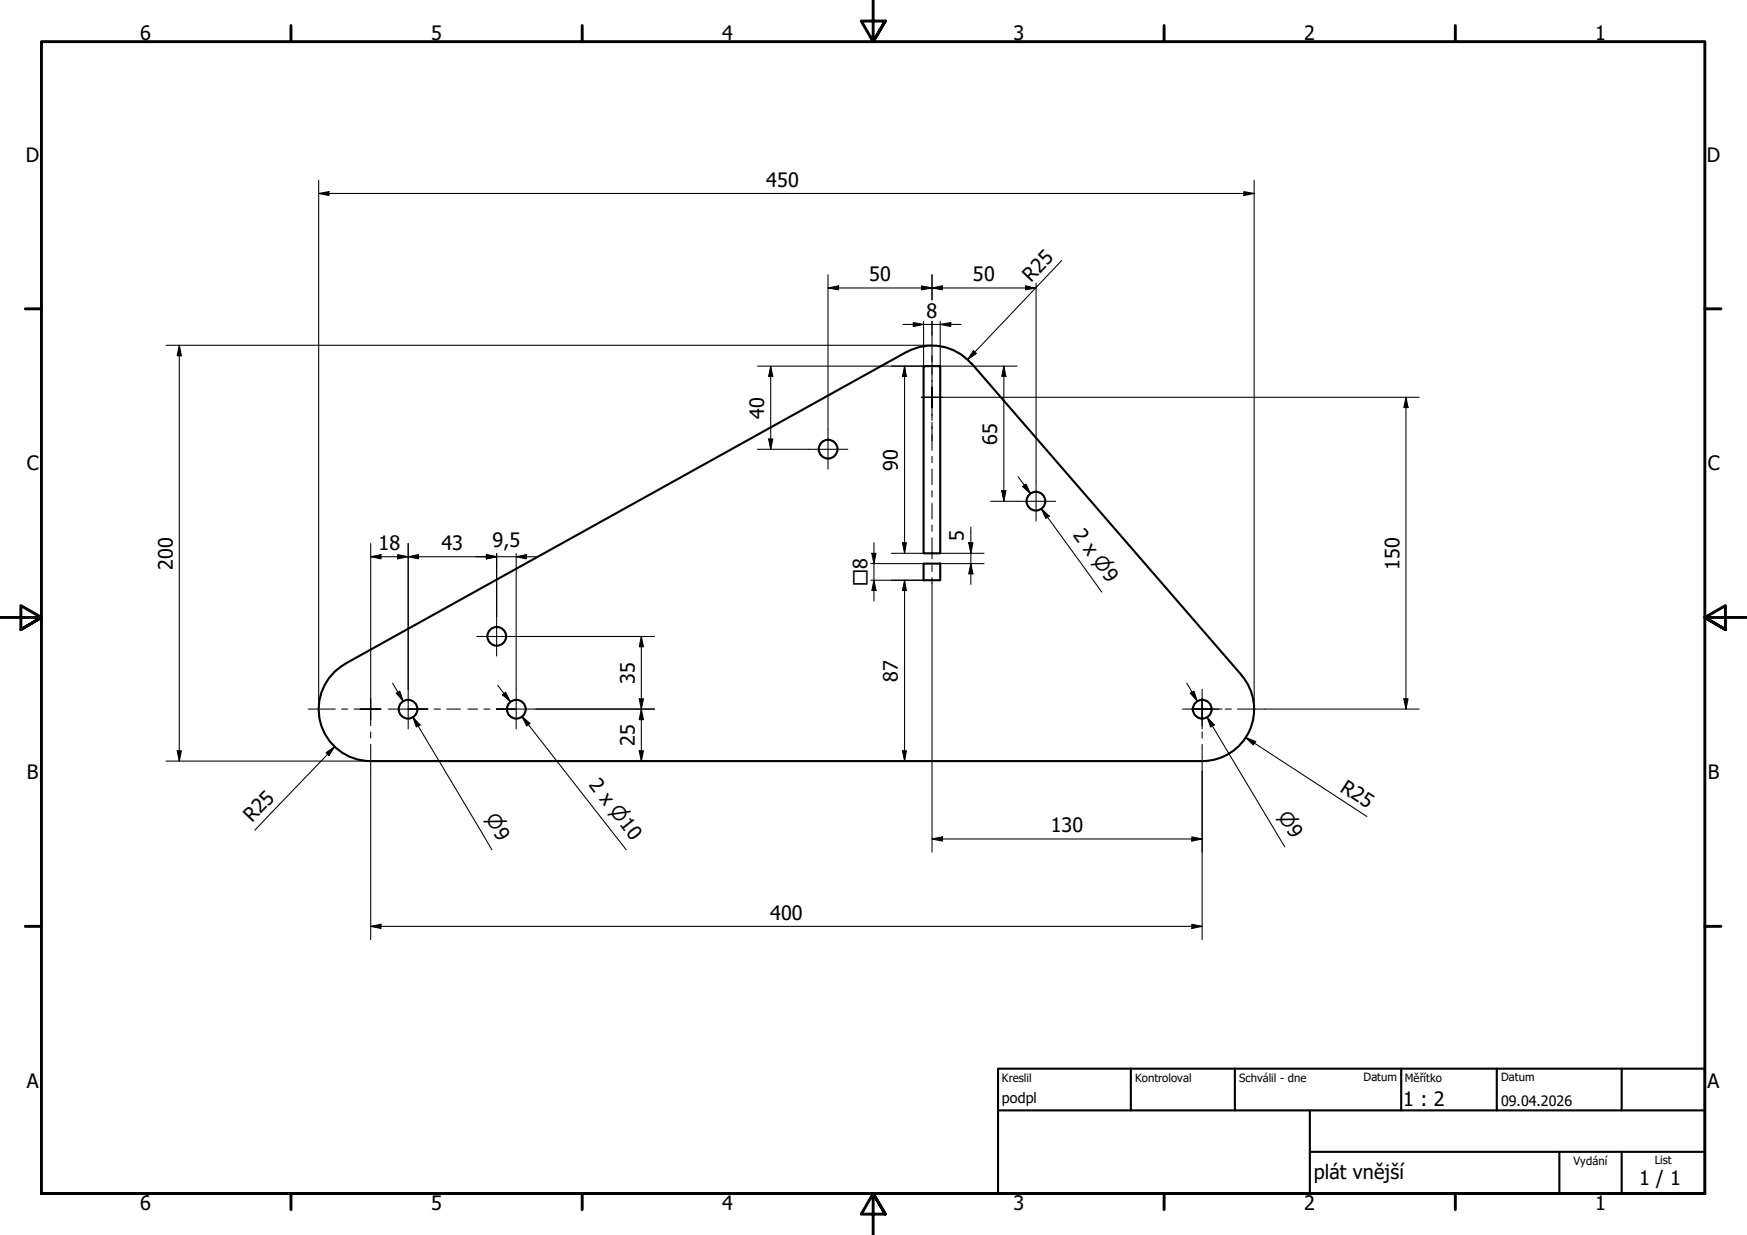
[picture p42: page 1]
plát vnější; Kreslil; Kontroloval; Schválil - dne; Datum

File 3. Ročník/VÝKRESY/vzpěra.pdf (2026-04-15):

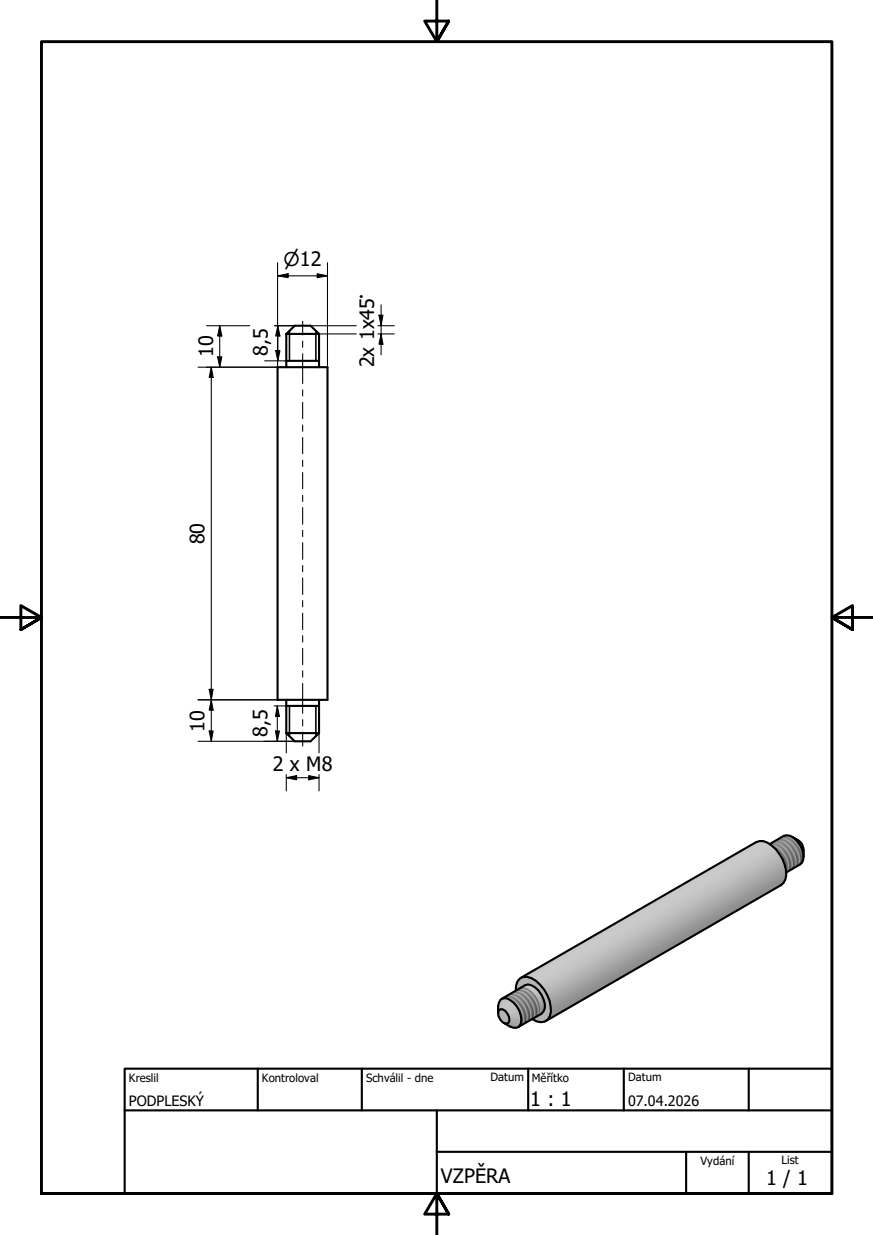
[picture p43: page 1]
Kreslil; Kontroloval; Schválil - dne; Datum

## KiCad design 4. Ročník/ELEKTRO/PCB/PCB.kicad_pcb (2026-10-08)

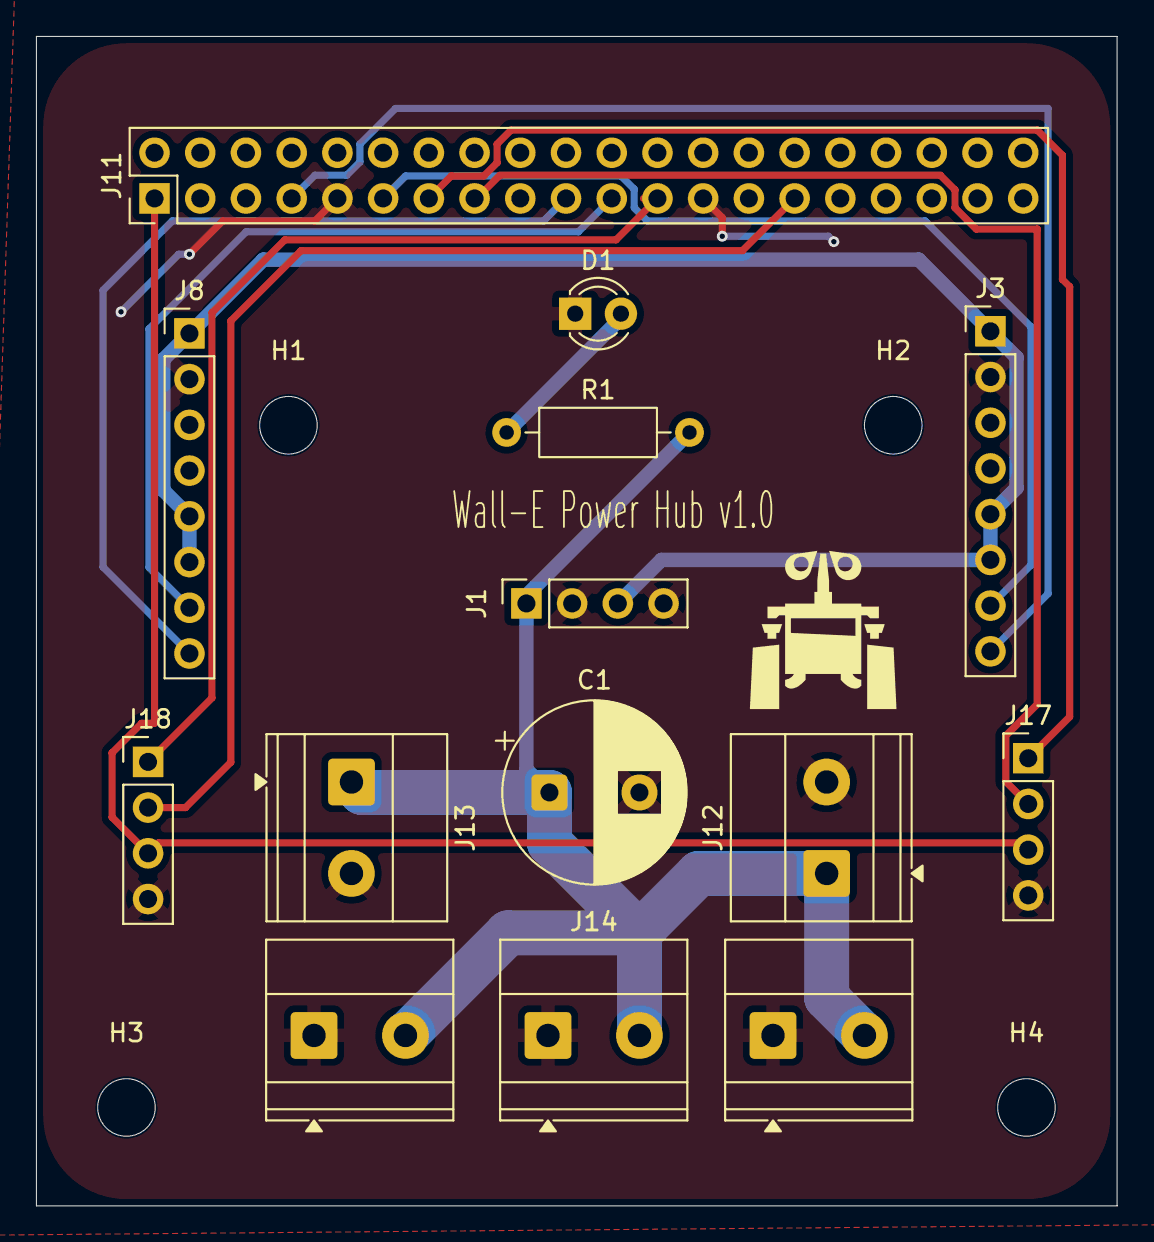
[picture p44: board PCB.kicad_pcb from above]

Board: 2 copper layers, 60.0 x 65.0 mm, 18 parts (0 on the bottom side), 13 nets.

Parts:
C1: 1000uF / 35V; CP_Radial_D10.0mm_P5.00mm
D1: LED; LED_D3.0mm
H1, H2, H3, H4: MountingHole; MountingHole_3.2mm_M3
J1: Conn_01x04; PinSocket_1x04_P2.54mm_Vertical
J3, J8: Conn_01x08; PinHeader_1x08_P2.54mm_Vertical
J11: Jetson Pinout; PinHeader_2x20_P2.54mm_Vertical
J12, J13, J14: Screw_Terminal_01x02; TerminalBlock_Phoenix_MKDS-1,5-2-5.08_1x02_P5.08mm_Horizont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
J15: Napajeni BTS_R; TerminalBlock_Phoenix_MKDS-1,5-2-5.08_1x02_P5.08mm_Horizont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
J16: Napajeni BTS_L; TerminalBlock_Phoenix_MKDS-1,5-2-5.08_1x02_P5.08mm_Horizont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
J17, J18: Conn_01x04; PinHeader_1x04_P2.54mm_Vertical
R1: 1k; R_Axial_DIN0207_L6.3mm_D2.5mm_P10.16mm_Horizontal

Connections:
+3V3: J11.1, J17.3, J18.3
+5V: J1.3, J3.1, J3.5, J3.6, J8.1, J8.5, J8.6
+12V: C1.1, J1.1, J12.1, J13.1, J14.2, J15.2, J16.2, R1.2
/L_LPWM: J8.8, J11.19
/L_RPWM: J8.7, J11.21
/MOTOR_L_ENK_A: J11.23, J18.1
/MOTOR_L_ENK_B: J11.29, J18.2
/MOTOR_R_ENK_A: J11.13, J17.1
/MOTOR_R_ENK_B: J11.15, J17.2
/R_LPWM: J3.8, J11.7
/R_RPWM: J3.7, J11.11
GND: C1.2, D1.1 (K), J1.2, J1.4, J3.2, J8.2, J11.9, J11.25, J12.2, J13.2, J14.1, J15.1, J16.1, J17.4, J18.4
unnamed: D1.2 (A), R1.1

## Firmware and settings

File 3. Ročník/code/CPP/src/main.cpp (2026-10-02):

#include <Arduino.h>
#include <Bluepad32.h>
#include "motor.h"
#include "encoder.h"
#define PIN_ENC_A_LEFT 10
#define PIN_ENC_B_LEFT 11
#define PIN_ENC_A_RIGHT 6
#define PIN_ENC_B_RIGHT 7
Motor motorLeft(8, 9, 0, 1);
Motor motorRight(4, 5, 2, 3);
Encoder encoderLeft(PIN_ENC_A_LEFT, PIN_ENC_B_LEFT);
Encoder encoderRight(PIN_ENC_A_RIGHT, PIN_ENC_B_RIGHT);
ControllerPtr myController = nullptr;
void onConnectedController(ControllerPtr ctl) {
    if (myController == nullptr) {
        Serial.println("KONTROLER PRIPOJEN!");
        myController = ctl;
        ControllerProperties properties = ctl->getProperties();
        Serial.printf("MAC adresa: %s\n", properties.btaddr);
    } else {
        Serial.println("Jiny kontroler pripojen, ale ignoruji ho (mame uz jeden).");
    }
}
void onDisconnectedController(ControllerPtr ctl) {
    if (myController == ctl) {
        Serial.println("KONTROLER ODPOJEN!");
        myController = nullptr;
        motorLeft.stop();
        motorRight.stop();
    }
}
const int BUZZER_PIN = 12;
int targetSpeedLeft = 0;
int targetSpeedRight = 0;
int currentSpeedLeft = 0;
int currentSpeedRight = 0;
const unsigned long ACCEL_DELAY_MS = 20;
void setup() {
    Serial.begin(115200);
    delay(3000);
    Serial.println("Startuji WALL-E Firmware...");
    motorLeft.begin();
    motorRight.begin();
    encoderLeft.begin();
    encoderRight.begin();
    BP32.setup(&onConnectedController, &onDisconnectedController);
    BP32.forgetBluetoothKeys();
    Serial.println("Cekam na pripojeni DualShocku (zmackni PS button)...");
}
void processKeyboard() {
    if (Serial.available() > 0) {
        char cmd = Serial.read();
        if (cmd == 'q' || cmd == 'Q') {
            Serial.println("LEVY PAS -> CIL DOPREDU!");
            targetSpeedLeft = 255;
        }
        else if (cmd == 'a' || cmd == 'A') {
            Serial.println("LEVY PAS -> CIL DOZADU!");
            targetSpeedLeft = -255;
        }
        else if (cmd == 'e' || cmd == 'E') {
            Serial.println("PRAVY PAS -> CIL DOPREDU!");
            targetSpeedRight = 255;
        }
        else if (cmd == 'd' || cmd == 'D') {
            Serial.println("PRAVY PAS -> CIL DOZADU!");
            targetSpeedRight = -255;
        }
        else if (cmd == ' ' || cmd == 's' || cmd == 'S') {
            Serial.println("NOUZOVY STOP OBA PASY!");
            targetSpeedLeft = 0;
            targetSpeedRight = 0;
            currentSpeedLeft = 0;
            currentSpeedRight = 0;
            motorLeft.stop();
            motorRight.stop();
        }
    }
    static unsigned long lastPrint = 0;
    if (millis() - lastPrint > 500) {
        Serial.printf("Rychlost L:%4d R:%4d | Enkoder L: %lld | R: %lld\n",
            currentSpeedLeft, currentSpeedRight, encoderLeft.getCount(), encoderRight.getCount());
        lastPrint = millis();
    }
}
void updateMotors() {
    static unsigned long lastUpdate = 0;
    if (millis() - lastUpdate >= ACCEL_DELAY_MS) {
        if (currentSpeedLeft < targetSpeedLeft) {
            currentSpeedLeft++;
        } else if (currentSpeedLeft > targetSpeedLeft) {
            currentSpeedLeft--;
        }
        if (currentSpeedRight < targetSpeedRight) {
            currentSpeedRight++;
        } else if (currentSpeedRight > targetSpeedRight) {
            currentSpeedRight--;
        }
        motorLeft.setSpeed(currentSpeedLeft);
        motorRight.setSpeed(currentSpeedRight);
        lastUpdate = millis();
    }
}
void loop() {
    processKeyboard();
    updateMotors();
    delay(5);
}

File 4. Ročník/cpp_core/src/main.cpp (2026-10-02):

#include <iostream>
#include <thread>
#include <atomic>
#include <chrono>
#include <cmath>
#include <hidapi/hidapi.h>
#include <linux/input.h>
#include <fcntl.h>
#include <unistd.h>
#include <algorithm>
#include "motor.h"

// Globální sdílené proměnné pro komunikaci mezi vlákny
std::atomic<float> left_pressure(0.0f);
std::atomic<float> right_pressure(0.0f);
std::atomic<int> direction_mode(1); // 1 = Dopředu, -1 = Dozadu
std::atomic<float> wheel_speed(0.0f); // 0 až 255.0
std::atomic<std::chrono::steady_clock::time_point> last_wheel_time;

// Globální přepínač zapnuto/vypnuto
std::atomic<bool> controls_enabled(true); 

// Vlákno pro vyčítání 10bitového tlaku přes Logitech HID++
void hidpp_thread() {
    hid_init();
    hid_device* dev = hid_open(0x046D, 0xC54D, NULL); // Zkusí Wireless přijímač
    if (!dev) dev = hid_open(0x046D, 0xC0A8, NULL); // Zkusí kabel
    
    if (!dev) {
        std::cerr << "Chyba: Nepodařilo se připojit k analogové myši přes HIDAPI.\n";
        return;
    }
    hid_set_nonblocking(dev, 1);
    
    auto last_lease = std::chrono::steady_clock::now() - std::chrono::seconds(10);
    unsigned char buf[64];
    
    while (true) {
        auto now = std::chrono::steady_clock::now();
        // Obnovování lease každé 2 vteřiny
        if (std::chrono::duration_cast<std::chrono::seconds>(now - last_lease).count() >= 2) {
            unsigned char report[20] = {0x11, 0xFF, 0x0C, 0x38, 0x02, 0x08}; 
            hid_write(dev, report, sizeof(report));
            report[1] = 0x01; 
            hid_write(dev, report, sizeof(report));
            last_lease = now;
        }

        int res = hid_read(dev, buf, sizeof(buf));
        if (res >= 20 && buf[0] == 0x11 && buf[2] == 0x0C && buf[3] == 0x10) {
            int left_raw = ((buf[4] << 8) | buf[5]) >> 6;
            int right_raw = ((buf[6] << 8) | buf[7]) >> 6;
            
            float lc = std::max(0, std::min(1000, left_raw - 300)) / 700.0f;
            float rc = std::max(0, std::min(1000, right_raw - 300)) / 700.0f;
            
            left_pressure.store(lc);
            right_pressure.store(rc);
        }
        std::this_thread::sleep_for(std::chrono::milliseconds(1));
    }
    hid_close(dev);
    hid_exit();
}

// Vlákno pro standardní tlačítka a kolečko z Linux Event rozhraní
void evdev_thread() {
    const char* dev_path = "/dev/input/event0"; // TODO: UPRAVIT NA VÁŠ SYSTÉM!
    int fd = open(dev_path, O_RDONLY | O_NONBLOCK);
    if (fd < 0) return;
    
    struct input_event ev;
    while (true) {
        if (read(fd, &ev, sizeof(ev)) > 0) {
            // Scrollování kolečkem
            if (ev.type == EV_REL && ev.code == REL_WHEEL) {
                float cur = wheel_speed.load();
                if (ev.value > 0) cur = std::min(255.0f, cur + 30.0f); // Dopředu
                if (ev.value < 0) cur = std::max(-255.0f, cur - 30.0f); // Dozadu
                wheel_speed.store(cur);
                last_wheel_time.store(std::chrono::steady_clock::now());
            }
            
            // Tlačítka myši
            if (ev.type == EV_KEY && ev.value == 1) { // 1 = Stisknuto (rising edge)
                // Stisknutí kolečka myši - Zastavení / Spuštění ovládání
                if (ev.code == BTN_MIDDLE) {
                    controls_enabled.store(!controls_enabled.load());
                    if (controls_enabled.load()) {
                        std::cout << "--- OVLADANI ZAPNUTO ---\n";
                    } else {
                        std::cout << "--- OVLADANI VYPNUTO (STOP) ---\n";
                    }
                }
                
                // Boční tlačítka pro směr pásů
                if (ev.code == BTN_SIDE) direction_mode.store(-1); // Zadní = Dozadu
                if (ev.code == BTN_EXTRA) direction_mode.store(1); // Přední = Dopředu
            }
        } else {
            std::this_thread::sleep_for(std::chrono::milliseconds(5));
        }
    }
    close(fd);
}

int main() {
    std::cout << "Inicializace robota Wall-E (Jetson C++ Port)...\n";
    std::cout << "Ovladani je defaultne ZAPNUTE. Pro nouzove zastaveni kliknete koleckem.\n";
    
    Motor left_motor(0, 1); 
    Motor right_motor(2, 3);
    left_motor.begin();
    right_motor.begin();

    std::thread t_hid(hidpp_thread);
    std::thread t_ev(evdev_thread);
    
    // Mrtvá zóna (Deadzone) - pod tuto hodnotu stisku motory nereagují
    const float DEADZONE = 0.08f; // 8% stisku
    
    while (true) {
        // Zastavení všech pohybů, pokud je ovládání vypnuté (stisknuto kolečko)
        if (!controls_enabled.load()) {
            wheel_speed.store(0.0f); // Vynulujeme i kolečko
            left_motor.setSpeed(0);
            right_motor.setSpeed(0);
            std::this_thread::sleep_for(std::chrono::milliseconds(20));
            continue;
        }

        float cur_wheel = wheel_speed.load();
        auto now = std::chrono::steady_clock::now();
        auto lw_time = last_wheel_time.load();
        auto diff_ms = std::chrono::duration_cast<std::chrono::milliseconds>(now - lw_time).count();

        // Plynulé zpomalení kolečka (po 0.5s bez točení)
        if (diff_ms > 500) {
            if (cur_wheel > 0) cur_wheel = std::max(0.0f, cur_wheel - 5.0f);
            if (cur_wheel < 0) cur_wheel = std::min(0.0f, cur_wheel + 5.0f);
            wheel_speed.store(cur_wheel);
        }

        int final_left = 0;
        int final_right = 0;

        // Kolečko přebíjí analogová tlačítka
        if (std::abs(cur_wheel) > 5.0f) {
            final_left = static_cast<int>(cur_wheel);
            final_right = static_cast<int>(cur_wheel);
        } else {
            float l_pres = left_pressure.load();
            float r_pres = right_pressure.load();

            // Aplikace mrtvé zóny (Blackzone/Deadzone) pro odstranění nechtěných lehkých dotyků
            if (l_pres < DEADZONE) l_pres = 0.0f;
            if (r_pres < DEADZONE) r_pres = 0.0f;

            int dir = direction_mode.load();
            final_left = static_cast<int>(l_pres * 255.0f) * dir;
            final_right = static_cast<int>(r_pres * 255.0f) * dir;
        }

        left_motor.setSpeed(final_left);
        right_motor.setSpeed(final_right);
        
        std::this_thread::sleep_for(std::chrono::milliseconds(20));
    }

    t_hid.join();
    t_ev.join();
    return 0;
}

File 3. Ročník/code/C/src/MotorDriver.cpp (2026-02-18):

#include "MotorDriver.h"
#include <iostream>
#include <cmath>
#include <algorithm>
#include <sys/ioctl.h>
#include <fcntl.h>
#include <unistd.h>
#include <linux/i2c-dev.h>

// Clamp helper
template <typename T>
T clamp(T val, T min, T max) {
    if (val < min) return min;
    if (val > max) return max;
    return val;
}

MotorDriver::MotorDriver(int i2c_bus, int i2c_addr) : i2c_address(i2c_addr) {
    char filename[20];
    snprintf(filename, 19, "/dev/i2c-%d", i2c_bus);
    i2c_fd = open(filename, O_RDWR);
    if (i2c_fd < 0) {
        std::cerr << "Error opening I2C bus: " << filename << std::endl;
    }
}

MotorDriver::~MotorDriver() {
    if (i2c_fd >= 0) {
        setTargetVelocity(0, 0);
        update(0.1); // Force stop
        close(i2c_fd);
    }
}

bool MotorDriver::init() {
    if (i2c_fd < 0) return false;

    if (ioctl(i2c_fd, I2C_SLAVE, i2c_address) < 0) {
        std::cerr << "Error selecting I2C device" << std::endl;
        return false;
    }

    // Reset PCA9685
    writeByte(PCA9685_MODE1, 0x00);
    
    // Set PWM frequency to ~50Hz (Standard analog servo / motor driver freq)
    // Formula: prescale = round(osc_clock / (4096 * update_rate)) - 1
    // osc_clock = 25MHz
    // 25000000 / (4096 * 50) - 1 = ~121
    uint8_t prescale = 121;
    
    uint8_t oldmode = readByte(PCA9685_MODE1);
    uint8_t newmode = (oldmode & 0x7F) | 0x10; // Sleep
    writeByte(PCA9685_MODE1, newmode);
    writeByte(PCA9685_PRESCALE, prescale);
    writeByte(PCA9685_MODE1, oldmode);
    usleep(5000);
    writeByte(PCA9685_MODE1, oldmode | 0xA1); // Auto-increment on

    return true;
}

void MotorDriver::setTargetVelocity(double linear, double angular) {
    target_linear = clamp(linear, -1.0, 1.0);
    target_angular = clamp(angular, -1.0, 1.0);
}

void MotorDriver::update(double dt) {
    // Ramping Linear
    double diff_lin = target_linear - current_linear;
    double max_delta_lin = max_accel_linear * dt;
    current_linear += clamp(diff_lin, -max_delta_lin, max_delta_lin);

    // Ramping Angular
    double diff_ang = target_angular - current_angular;
    double max_delta_ang = max_accel_angular * dt;
    current_angular += clamp(diff_ang, -max_delta_ang, max_delta_ang);

    // Differential Drive Mixing
    // Left = Linear - Angular
    // Right = Linear + Angular
    // (Signs depend on motor orientation, adjust here if needed)
    double left_speed = current_linear - current_angular;
    double right_speed = current_linear + current_angular;

    // Normalize if exceeding 1.0 to preserve ratio (optional, but good for turning at high speed)
    double max_mag = std::max(std::abs(left_speed), std::abs(right_speed));
    if (max_mag > 1.0) {
        left_speed /= max_mag;
        right_speed /= max_mag;
    }

    setMotorL(left_speed);
    setMotorR(right_speed);
}

// Low-level PCA9685 PWM sets
// Channels assumed from schematic:
// CH0: L_FWD, CH1: L_BWD
// CH2: R_FWD, CH3: R_BWD
void MotorDriver::setMotorL(double speed) {
    uint16_t pwm_val = (uint16_t)(std::abs(speed) * 4095.0);
    if (speed > 0) {
        setPWM(0, 0, pwm_val); // L_FWD
        setPWM(1, 0, 0);       // L_BWD OFF
    } else {
        setPWM(0, 0, 0);       // L_FWD OFF
        setPWM(1, 0, pwm_val); // L_BWD
    }
}

void MotorDriver::setMotorR(double speed) {
    uint16_t pwm_val = (uint16_t)(std::abs(speed) * 4095.0);
    if (speed > 0) {
        setPWM(2, 0, pwm_val); // R_FWD
        setPWM(3, 0, 0);       // R_BWD OFF
    } else {
        setPWM(2, 0, 0);       // R_FWD OFF
        setPWM(3, 0, pwm_val); // R_BWD
    }
}

void MotorDriver::writeByte(uint8_t reg, uint8_t data) {
    uint8_t buf[2] = {reg, data};
    write(i2c_fd, buf, 2);
}

uint8_t MotorDriver::readByte(uint8_t reg) {
    if (write(i2c_fd, &reg, 1) != 1) return 0;
    uint8_t data;
    if (read(i2c_fd, &data, 1) != 1) return 0;
    return data;
}

void MotorDriver::setPWM(int channel, uint16_t on, uint16_t off) {
    uint8_t reg = LED0_ON_L + 4 * channel;
    uint8_t data[5];
    data[0] = reg;
    data[1] = on & 0xFF;
    data[2] = on >> 8;
    data[3] = off & 0xFF;
    data[4] = off >> 8;
    write(i2c_fd, data, 5);
}

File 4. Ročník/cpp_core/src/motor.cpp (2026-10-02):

#include "motor.h"
#include <iostream>
#include <fstream>
#include <cmath>

Motor::Motor(int channel_l, int channel_r) {
    pwmChannelL = channel_l;
    pwmChannelR = channel_r;
    
    // Na Jetsonu se k hardwarovému PWM běžně přistupuje přes sysfs: /sys/class/pwm/pwmchipX
    // Cesty si budete muset případně upravit podle toho, jaké piny na Jetsonu fyzicky použijete
    pwmBasePathL = "/sys/class/pwm/pwmchip0/pwm" + std::to_string(pwmChannelL);
    pwmBasePathR = "/sys/class/pwm/pwmchip0/pwm" + std::to_string(pwmChannelR);
}

bool Motor::writeSysfs(const std::string& path, const std::string& filename, const std::string& value) {
    std::ofstream file(path + "/" + filename);
    if (!file.is_open()) return false;
    file << value;
    return true;
}

void Motor::begin() {
    // Export PWM (pokud už není)
    std::ofstream exportFileL("/sys/class/pwm/pwmchip0/export");
    if(exportFileL.is_open()) exportFileL << pwmChannelL;
    
    std::ofstream exportFileR("/sys/class/pwm/pwmchip0/export");
    if(exportFileR.is_open()) exportFileR << pwmChannelR;

    // Nastavení periody (v nanosekundách) - 20000000 ns = 50 Hz, 1000000 ns = 1kHz
    writeSysfs(pwmBasePathL, "period", "1000000"); 
    writeSysfs(pwmBasePathR, "period", "1000000");

    writeSysfs(pwmBasePathL, "enable", "1");
    writeSysfs(pwmBasePathR, "enable", "1");
    
    stop();
}

void Motor::setSpeed(int speed) {
    if (speed > 255) speed = 255;
    if (speed < -255) speed = -255;
    
    if (std::abs(speed) < 15) {
        stop();
        return;
    }
    
    // Přepočet rychlosti 0-255 na duty_cycle v nanosekundách (0 - 1000000)
    int duty_ns = (std::abs(speed) * 1000000) / 255;
    
    if (speed > 0) {
        writeSysfs(pwmBasePathR, "duty_cycle", "0");
        writeSysfs(pwmBasePathL, "duty_cycle", std::to_string(duty_ns));
    } else {
        writeSysfs(pwmBasePathL, "duty_cycle", "0");
        writeSysfs(pwmBasePathR, "duty_cycle", std::to_string(duty_ns));
    }
}

void Motor::stop() {
    writeSysfs(pwmBasePathL, "duty_cycle", "0");
    writeSysfs(pwmBasePathR, "duty_cycle", "0");
}

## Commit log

2025-11-13 Creating files, DWG and research
    [obecné kótování.dwg]
2025-11-25 Add camera link to random komponenty
2025-12-10 Frame.stl created
    [Frame.stl, obecné kótování.dwg]
2026-02-16 Remove comments from components list
    Removed comments about motor robustness and driver logic level requirements.
2026-04-01 Update .gitignore: Ignore .agents, workspace, AUTOCAD, Blueprint
    [Frame.stl, obecné kótování.dwg]
2026-04-03 Obnova dwg souborů a modelů - přesunuto do VÝKRESY
    [Frame.stl, obecné kótování.dwg]
2026-04-03 Obnova výkresu spodního kusu z cache (OldVersions)
    [kus spodní.dwg]
2026-04-14 Aktualizace CAD modelů, přidání STEP, STL a výkresů
    [Těleso1.stl, hnací kolo.step, hnací kolo.stl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]
2026-04-15 Revize a kompletace CAD výkresů pro Wall-E (Materiály, tolerance, STEP modely, PDF)
    [hnací kolo.dwg, hnací kolo.ipt, kolo zadní_.ipt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]
2026-04-23 feat(firmware): Initialize ESP32-S3 PlatformIO project and backup old C code
    [.kicad_sch, .kicad_sch.kicad_sch, Distanční váleček 10.step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]
2026-06-16 Add documentation for encoders and MicroPython example
    Added detailed explanation of encoders, including types, working principles, and example code in MicroPython for reading rotary encoders using interrupts.
2026-06-16 Enhance nevim.md with encoder examples and formatting
    Updated text formatting and added code examples for encoder handling in MicroPython.
2026-10-02 Přechod na maturitní práci - Jetson C++ a myš
    [.kicad_sch, .kicad_sch.kicad_sch, Distanční váleček 10.step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]
2026-10-04 Dokončen návrh řídící desky Power Hub v1.0 (KiCad)
    [PCB.kicad_pcb, PCB.kicad_sch]
2026-10-08 PCB v1.0 fixes: 0.4/0.8mm routing, GND plane pour, silkscreen updates
    [DC-Fan-40x40x10.stl, PCB.kicad_pcb, PCB.kicad_sch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]
2026-10-15 Add napady.txt and update PCB files
2026-10-23 Update chassis design: top drive sprocket with chain, bellcrank suspension with eccentric tension compensation, 3-bogie road wheels
2026-10-23 Update PREHLED_PROGRESS_A_PLANY.md: GT2 belt kinematics, centered track geometry, integrated pulley, Copilot skills
2026-11-02 Aktualizace .gitignore pro CAD a KiCad soubory
2026-11-02 Ignore KiCad history backups
    Remove accidental history gitlinks while preserving the local backup folders.
2026-11-03 Update chassis suspension progress
    Record the current concepts for sprung idlers, fixed lower support rollers, and the 90-degree drive module.
